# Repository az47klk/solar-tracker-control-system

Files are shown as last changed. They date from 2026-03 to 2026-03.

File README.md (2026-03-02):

# Solar-Tracker: Güneş Paneli Güç Takip ve Kontrol Sistemi

Bu proje, hareketli güneş paneli sistemlerinin güvenli şekilde çalışmaları için, anlık güç takibi yapmak ve çevresel verileri (sıcaklık, zaman vb.) yönetmek amacıyla geliştirilmiş bir gömülü kontrol sistemidir. Proje; donanım tasarımı (PCB), düşük seviyeli sürücü yazılımı ve endüstriyel haberleşme protokollerini kapsamaktadır.

resim

## Teknik Özellikler
Sistem, endüstriyel standart gereksinimleri dikkate alınarak tasarlanmıştır:

* **Kontrol Birimi:** STM32 Mikrodenetleyici tabanlı mimari 
* **Haberleşme:** * **RS485 (Modbus):** Uzak mesafe veri iletimi ve endüstriyel cihaz entegrasyonu.
    * **I2C & UART:** Sensör ve çevre birimleri ile iletişim.
* **Donanım Bileşenleri:**
    * **MAX485:** Diferansiyel sinyal işleme ve gürültü bağışıklığı.
    * **DS1307 RTC:** Gerçek zamanlı saat takibi ile zaman bazlı hareket senaryoları.
    * **JW2 Röle Kontrolü:** Panel hareket mekanizması için güç yönetimi.
    * **128x64 OLED:** Yerel kullanıcı arayüzü ve anlık veri izleme.
* **PCB Tasarımı:** **KiCad** kullanılarak hazırlanan, sinyal bütünlüğü ve güç dağıtımı optimize edilmiş özgün devre kartı.

## Donanım Mimarisi
Proje kapsamında geliştirilen güç takip kartı şu işlevleri yerine getirmektedir:
1.  **Veri Toplama:** Sıcaklık sensörlerinden gelen verilerin işlenmesi.
2.  **Güç Yönetimi:** Röle katmanı üzerinden motor sürücülerin kontrol edilmesi.
3.  **HMI Entegrasyonu:** Sistem durumunun (gerilim, akım, zaman, sıcaklık) OLED ekran üzerinde gösterilmesi.
4.  **Haberleşme Katmanı:** Toplanan verilerin RS485 üzerinden merkezi bir birime aktarılması.

## Dosya Yapısı
* `/Hardware`: KiCad şema ve PCB tasarım dosyaları (Gerber dahil).
* `/Software`: C++ ile geliştirilen kontrol yazılımı ve sürücü kütüphaneleri.

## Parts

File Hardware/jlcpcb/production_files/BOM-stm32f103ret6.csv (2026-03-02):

Comment | Designator | Footprint | LCSC | Quantity
0.5R | R21 | R_2512_6332Metric | C105142 | 1
1.2k | R4 | R_0603_1608Metric | C22765 | 1
1.5M | R23 | R_0603_1608Metric | C1203 | 1
100R | R13,R17 | R_0603_1608Metric | C22775 | 2
100k | R12,R16 | R_0603_1608Metric | C15458 | 2
100nF | C12,C2,C21 | C_0402_1005Metric | C1525 | 3
100nF | C1,C10,C11,C13,C14,C7,C8,C9 | C_0603_1608Metric | C1590 | 8
10k | R2,R6,R8,R9 | R_0603_1608Metric | C15401 | 4
10k | R11,R14,R15,R3,R7 | R_0402_1005Metric | C25531 | 5
10uF | C17,C18,C3 | CP_EIA-3216-18_Kemet-A | C7171 | 3
120R | R5 | R_0603_1608Metric_Pad0.98x0.95mm_HandSolder | C22787 | 1
180R | R19 | R_0603_1608Metric | C22828 | 1
1N4148W | D6 | D_SOD-123 | C2099 | 1
1uF | C15,C19 | C_0603_1608Metric | C1592 | 2
200R | R26 | R_0603_1608Metric | C8218 | 1
20k | R10 | R_0402_1005Metric | C25545 | 1
220uF | C16 | CP_Elec_6.3x7.7 | C3342 | 1
3.3k | R18 | R_0402_1005Metric | C25890 | 1
30pF | C5,C6 | C_0603_1608Metric | C1658 | 2
32768Hz | Y1 | Crystal_SMD_3215-2Pin_3.2x1.5mm | C182057 | 1
330R | R1 | R_0603_1608Metric | C22104 | 1
33uH | L1 | L_Wuerth_HCM-1052 | C9186 | 1
470k | R25 | R_0603_1608Metric | C25599 | 1
680uF | C4 | CP_Elec_12.5x13.5 | C98216 | 1
8MHz_Crystal | Y2 | Crystal_SMD_5032-2Pin_5.0x3.2mm | C115962 | 1
ACPL-P340 | U8 | SO-6L_10x3.84mm_P1.27mm | C74960 | 1
AMS1117-3.3 | U6 | SOT-223-3_TabPin2 | C6186 | 1
AO3400A | Q1 | SOT-23 | C20917 | 1
AT24C512C | U1 | SOP-8_3.76x4.96mm_P1.27mm | C19723714 | 1
Battery_Cell | BT1 | CR2032_battery | C962133 | 1
Conn_01x02 | J2 | PhoenixContact_MSTBA_2,5_2-G-5,08_1x02_P5.08mm_Horizontal | C3697 | 1
Conn_01x03 | J1,J3 | PhoenixContact_MSTBA_2,5_3-G-5,08_1x03_P5.08mm_Horizontal | C8377 | 2
Conn_02x06 | J5 | IDC-Header_2x06_P2.54mm_Vertical | C5307342 | 1
D | D2 | D_SMB | C15874 | 1
DS1307Z+ | U5 | SOIC-8_3.9x4.9mm_P1.27mm | C9868 | 1
DS1621 | U4 | SOIC-8_3.9x4.9mm_P1.27mm | C407894 | 1
INA226 | U9 | VSSOP-10_3x3mm_P0.5mm | C49851 | 1
LED | D1,D3,D4 | LED_0805_2012Metric | C94868 | 3
LM2596S-5 | U7 | TO-263-5_TabPin3 | C2980820 | 1
MAX485ESA+T | U2 | SOIC-8_3.9x4.9mm_P1.27mm | C19738 | 1
SS14 | D5 | D_SMA | C2480 | 1
SS34 | D7 | D_SMA | C8678 | 1
STM32F103RETx | U3 | LQFP-64_10x10mm_P0.5mm | C1337363 | 1
JW2 | RL1 | Relay_DPDT_Panasonic_JW2 |  | 1
Conn_01x05 | J4 | PinHeader_1x05_P2.54mm_Vertical |  | 1

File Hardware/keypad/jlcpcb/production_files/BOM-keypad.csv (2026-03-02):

Comment | Designator | Footprint | LCSC | Quantity
100R | R4,R5,R6,R7 | R_0603_1608Metric | C22775 | 4
100nF | C1,C2,C3,C4 | C_0402_1005Metric | C1525 | 4
10k | R1,R12,R2,R3 | R_0603_1608Metric | C15401 | 4
Conn_01x04_Pin | J1 | PinHeader_1x04_P2.54mm_Vertical | C5116530 | 1
Conn_02x06_Counter_Clockwise | J5 | IDC-Header_2x06_P2.54mm_Vertical | C5224012 | 1
LED | D1,D2,D3,D4 | LED_0805_2012Metric | C2296 | 4
SW_Push | SW4 | SW_PUSH_6mm |  | 1
SW_Push | SW2 | SW_PUSH_6mm |  | 1
SW_Push | SW3 | SW_PUSH_6mm |  | 1
SW_Push | SW1 | SW_PUSH_6mm |  | 1

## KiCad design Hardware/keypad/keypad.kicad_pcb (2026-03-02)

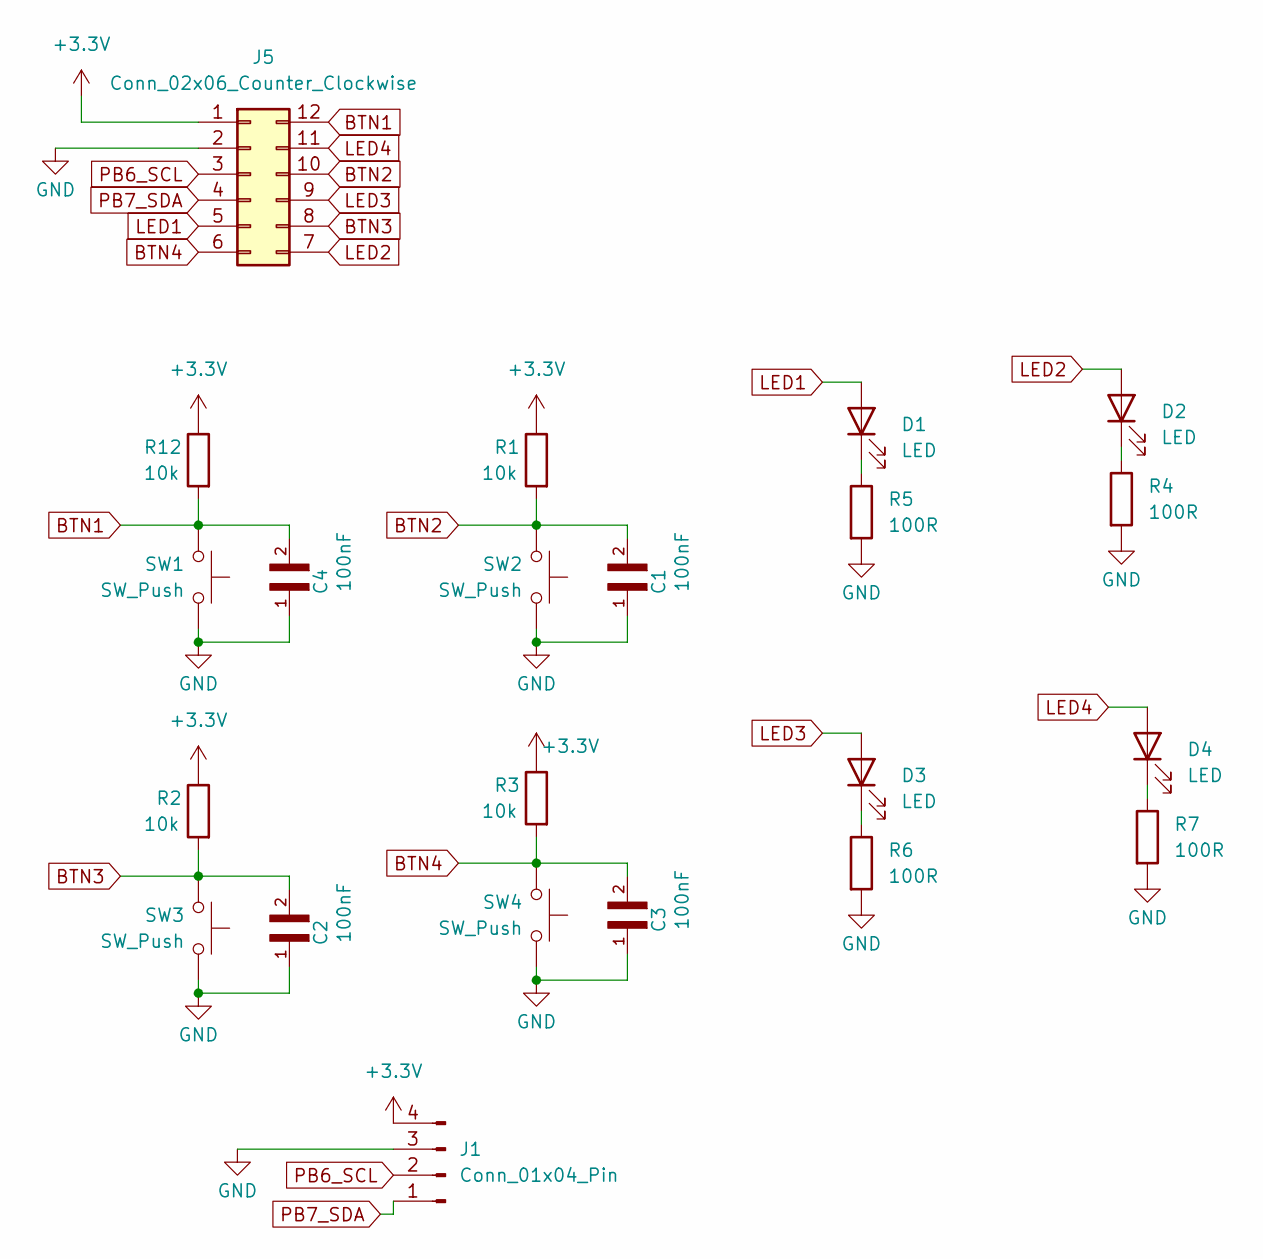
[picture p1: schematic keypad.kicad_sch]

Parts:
C1, C2, C3, C4: 100nF; C_0402_1005Metric
D1, D2, D3, D4: LED; LED_0805_2012Metric
J1: Conn_01x04_Pin; PinHeader_1x04_P2.54mm_Vertical
J5: Conn_02x06_Counter_Clockwise; IDC-Header_2x06_P2.54mm_Vertical
R1, R2, R3, R12: 10k; R_0603_1608Metric
R4, R5, R6, R7: 100R; R_0603_1608Metric
SW1, SW2, SW3, SW4: SW_Push; SW_PUSH_6mm

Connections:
+3.3V: J1.4, J5.1, R1.1, R2.1, R3.1, R12.1
BTN1: C4.2, J5.12, R12.2, SW1.2
BTN2: C1.2, J5.10, R1.2, SW2.2
BTN3: C2.2, J5.8, R2.2, SW3.2
BTN4: C3.2, J5.6, R3.2, SW4.2
GND: C1.1, C2.1, C3.1, C4.1, J1.3, J5.2, R4.2, R5.2, R6.2, R7.2, SW1.1, SW2.1, SW3.1, SW4.1
LED1: D1.2 (A), J5.5
LED2: D2.2 (A), J5.7
LED3: D3.2 (A), J5.9
LED4: D4.2 (A), J5.11
unnamed: D1.1 (K), R5.1
unnamed: D2.1 (K), R4.1
unnamed: D3.1 (K), R6.1
unnamed: D4.1 (K), R7.1
PB6_SCL: J1.2, J5.3
PB7_SDA: J1.1, J5.4

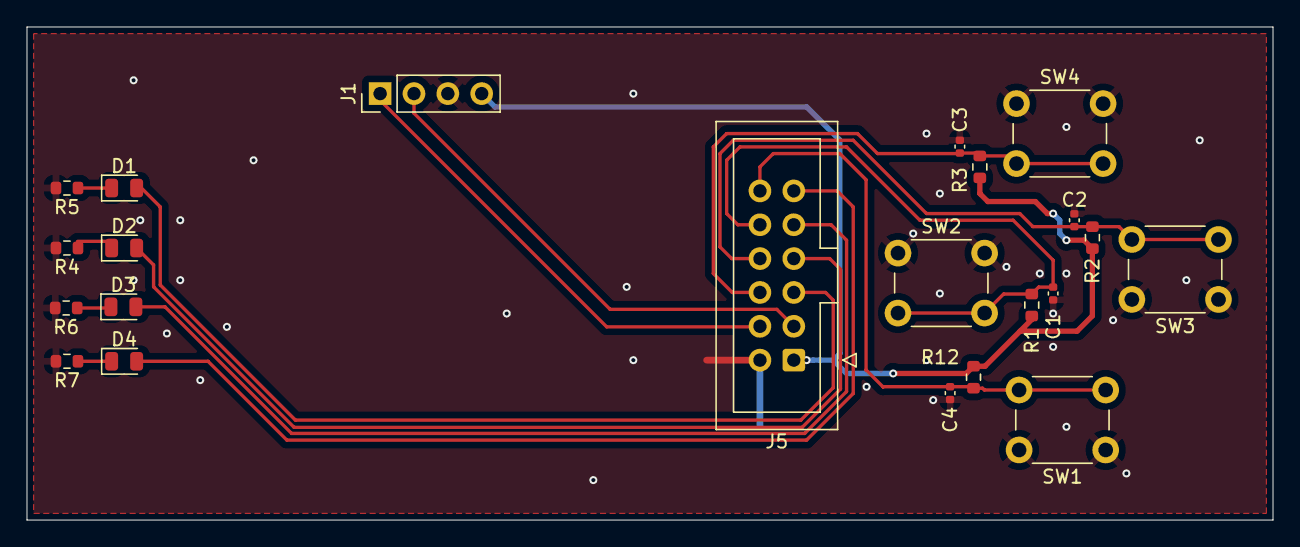
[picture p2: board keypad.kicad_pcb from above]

Board: 2 copper layers, 93.5 x 37.0 mm, 22 parts (0 on the bottom side), 16 nets.

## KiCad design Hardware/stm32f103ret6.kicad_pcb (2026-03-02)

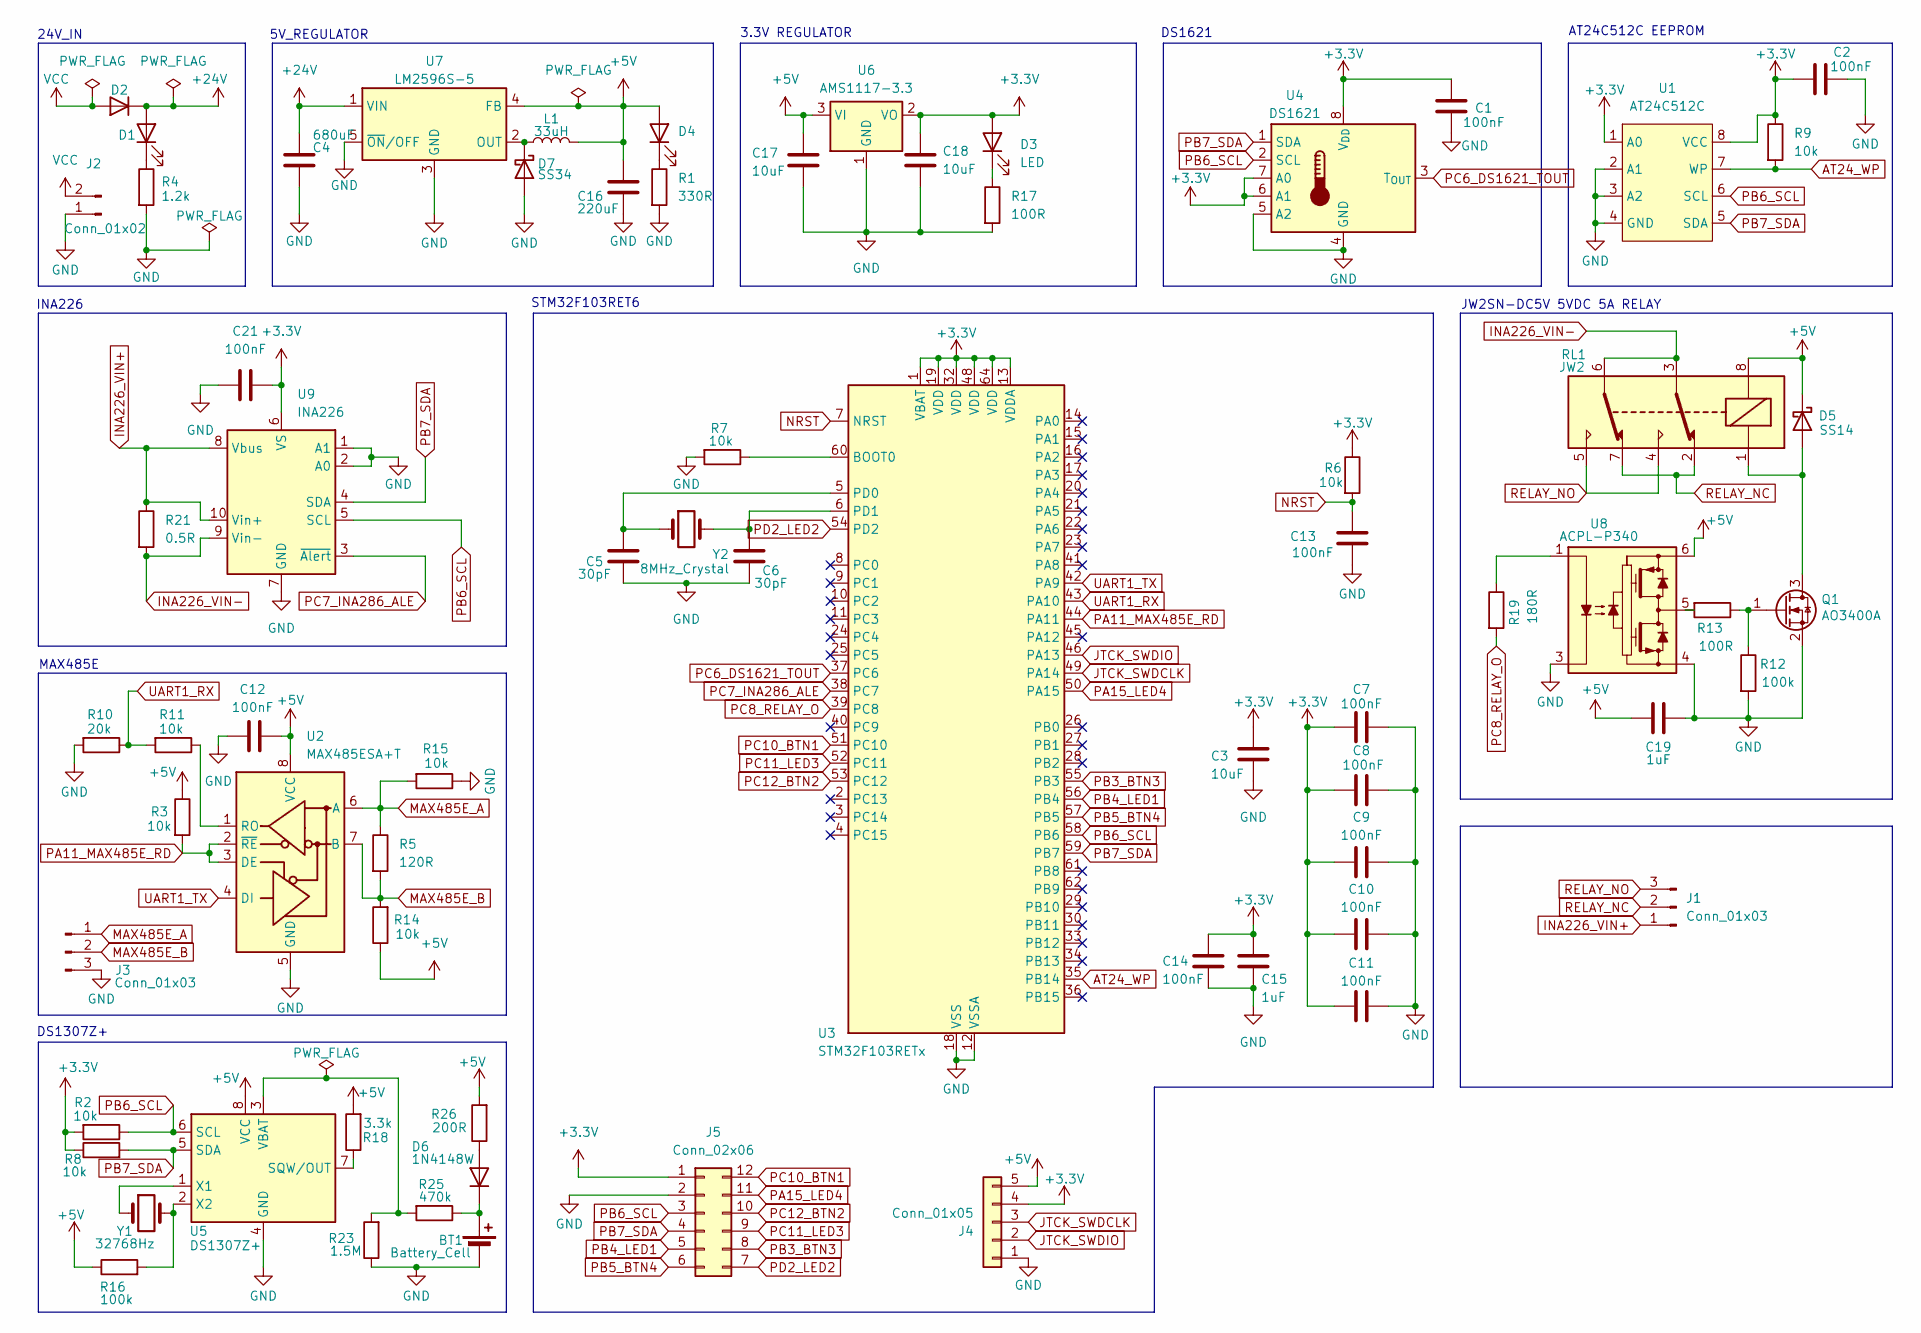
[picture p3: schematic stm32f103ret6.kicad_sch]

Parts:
BT1: Battery_Cell; CR2032_battery
C1, C7, C8, C9, C10, C11, C13, C14: 100nF; C_0603_1608Metric
C2, C12, C21: 100nF; C_0402_1005Metric
C3, C17, C18: 10uF; CP_EIA-3216-18_Kemet-A
C4: 680uF; CP_Elec_12.5x13.5
C5, C6: 30pF; C_0603_1608Metric
C15, C19: 1uF; C_0603_1608Metric
C16: 220uF; CP_Elec_6.3x7.7
D1, D3, D4: LED; LED_0805_2012Metric
D2: D; D_SMB
D5: SS14; D_SMA
D6: 1N4148W; D_SOD-123
D7: SS34; D_SMA
J1, J3: Conn_01x03; PhoenixContact_MSTBA_2,5_3-G-5,08_1x03_P5.08mm_Horizontal
J2: Conn_01x02; PhoenixContact_MSTBA_2,5_2-G-5,08_1x02_P5.08mm_Horizontal
J4: Conn_01x05; PinHeader_1x05_P2.54mm_Vertical
J5: Conn_02x06; IDC-Header_2x06_P2.54mm_Vertical
L1: 33uH; L_Wuerth_HCM-1052
Q1: AO3400A; SOT-23
R1: 330R; R_0603_1608Metric
R2, R6, R8, R9: 10k; R_0603_1608Metric
R3, R7, R11, R14, R15: 10k; R_0402_1005Metric
R4: 1.2k; R_0603_1608Metric
R5: 120R; R_0603_1608Metric_Pad0.98x0.95mm_HandSolder
R10: 20k; R_0402_1005Metric
R12, R16: 100k; R_0603_1608Metric
R13, R17: 100R; R_0603_1608Metric
R18: 3.3k; R_0402_1005Metric
R19: 180R; R_0603_1608Metric
R21: 0.5R; R_2512_6332Metric
R23: 1.5M; R_0603_1608Metric
R25: 470k; R_0603_1608Metric
R26: 200R; R_0603_1608Metric
RL1: JW2; Relay_DPDT_Panasonic_JW2
U1: AT24C512C; SOP-8_3.76x4.96mm_P1.27mm
U2: MAX485ESA+T; SOIC-8_3.9x4.9mm_P1.27mm
U3: STM32F103RETx; LQFP-64_10x10mm_P0.5mm
U4: DS1621; SOIC-8_3.9x4.9mm_P1.27mm
U5: DS1307Z+; SOIC-8_3.9x4.9mm_P1.27mm
U6: AMS1117-3.3; SOT-223-3_TabPin2
U7: LM2596S-5; TO-263-5_TabPin3
U8: ACPL-P340; SO-6L_10x3.84mm_P1.27mm
U9: INA226; VSSOP-10_3x3mm_P0.5mm
Y1: 32768Hz; Crystal_SMD_3215-2Pin_3.2x1.5mm
Y2: 8MHz_Crystal; Crystal_SMD_5032-2Pin_5.0x3.2mm

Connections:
+3.3V: C1.2, C2.1, C3.1, C7.2, C8.2, C9.2, C10.2, C11.2, C14.1, C15.1, C18.1, C21.2, D3.2 (A), J4.4, J5.1, R2.2, R6.1, R8.1, R9.1, U1.1 (A0), U1.8 (VCC), U3.1 (VBAT), U3.13 (VDDA), U3.19 (VDD), U3.32 (VDD), U3.48 (VDD), U3.64 (VDD), U4.6 (A1), U4.7 (A0), U4.8 (V_{DD}), U6.2 (VO), U9.6 (VS)
+5V: C12.2, C16.1, C17.1, C19.2, D4.2 (A), D5.1 (K), J4.5, L1.2, R3.1, R14.1, R16.1, R18.2, R26.2, RL1.8, U2.8 (VCC), U5.8 (VCC), U6.3 (VI), U7.4 (FB), U8.6 (VCC)
+24V: C4.1, D1.2 (A), D2.1 (K), U7.1 (VIN)
AT24_WP: R9.2, U1.7 (WP), U3.35 (PB14)
GND: BT1.2 (-), C1.1, C2.2, C3.2, C4.2, C5.2, C6.2, C7.1, C8.1, C9.1, C10.1, C11.1, C12.1, C13.2, C14.2, C15.2, C16.2, C17.2, C18.2, C19.1, C21.1, D7.2 (A), J2.1, J3.3, J4.1, J5.2, Q1.2 (S), R1.2, R4.2, R7.2, R10.2, R12.2, R15.1, R17.2, R23.1, U1.2 (A1), U1.3 (A2), U1.4 (GND), U2.5 (GND), U3.12 (VSSA), U3.18 (VSS), U3.31 (VSS), U3.47 (VSS), U3.63 (VSS), U4.4 (GND), U4.5 (A2), U5.4 (GND), U6.1 (GND), U7.3 (GND), U7.5 (~ON/OFF), U8.3 (C), U8.4 (VEE), U9.1 (A1), U9.2 (A0), U9.7 (GND)
INA226_VIN+: J1.1, R21.1, U9.8 (Vbus), U9.10 (Vin+)
INA226_VIN-: R21.2, RL1.3, RL1.6, U9.9 (Vin-)
JTCK_SWDCLK: J4.3, U3.49 (PA14)
JTCK_SWDIO: J4.2, U3.46 (PA13)
MAX485E_A: J3.1, R5.1, R15.2, U2.6 (A)
MAX485E_B: J3.2, R5.2, R14.2, U2.7 (B)
NRST: C13.1, R6.2, U3.7 (NRST)
unnamed: BT1.1 (+), D6.1 (K), R25.1
unnamed: D1.1 (K), R4.1
unnamed: D3.1 (K), R17.1
unnamed: D4.1 (K), R1.1
unnamed: D5.2 (A), Q1.3 (D), RL1.1
unnamed: D6.2 (A), R26.1
unnamed: D7.1 (K), L1.1, U7.2 (OUT)
unnamed: Q1.1 (G), R12.1, R13.1
unnamed: R11.1, U2.1 (RO)
unnamed: R7.1, U3.60 (BOOT0)
unnamed: C5.1, U3.5 (PD0), Y2.1
unnamed: C6.1, U3.6 (PD1), Y2.2
unnamed: R18.1, U5.7 (SQW/OUT)
unnamed: R23.2, R25.2, U5.3 (VBAT)
unnamed: U5.1 (X1), Y1.1
unnamed: R16.2, U5.2 (X2), Y1.2
unnamed: R19.1, U8.1 (A)
unnamed: R13.2, U8.5 (VO)
PA11_MAX485E_RD: R3.2, U2.2 (~RE), U2.3 (DE), U3.44 (PA11)
PA15_LED4: J5.11, U3.50 (PA15)
PB3_BTN3: J5.8, U3.55 (PB3)
PB4_LED1: J5.5, U3.56 (PB4)
PB5_BTN4: J5.6, U3.57 (PB5)
PB6_SCL: J5.3, R2.1, U1.6 (SCL), U3.58 (PB6), U4.2 (SCL), U5.6 (SCL), U9.5 (SCL)
PB7_SDA: J5.4, R8.2, U1.5 (SDA), U3.59 (PB7), U4.1 (SDA), U5.5 (SDA), U9.4 (SDA)
PC6_DS1621_TOUT: U3.37 (PC6), U4.3 (T_{OUT})
PC7_INA286_ALE: U3.38 (PC7), U9.3 (~Alert)
PC8_RELAY_O: R19.2, U3.39 (PC8)
PC10_BTN1: J5.12, U3.51 (PC10)
PC11_LED3: J5.9, U3.52 (PC11)
PC12_BTN2: J5.10, U3.53 (PC12)
PD2_LED2: J5.7, U3.54 (PD2)
RELAY_NC: J1.2, RL1.2, RL1.7
RELAY_NO: J1.3, RL1.4, RL1.5
UART1_RX: R10.1, R11.2, U3.43 (PA10)
UART1_TX: U2.4 (DI), U3.42 (PA9)
VCC: D2.2 (A), J2.2

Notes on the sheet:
STM32F103RET6
MAX485E
JW2SN-DC5V 5VDC 5A RELAY
3.3V REGULATOR
5V_REGULATOR
24V_IN
AT24C512C EEPROM
DS1621
DS1307Z+
INA226

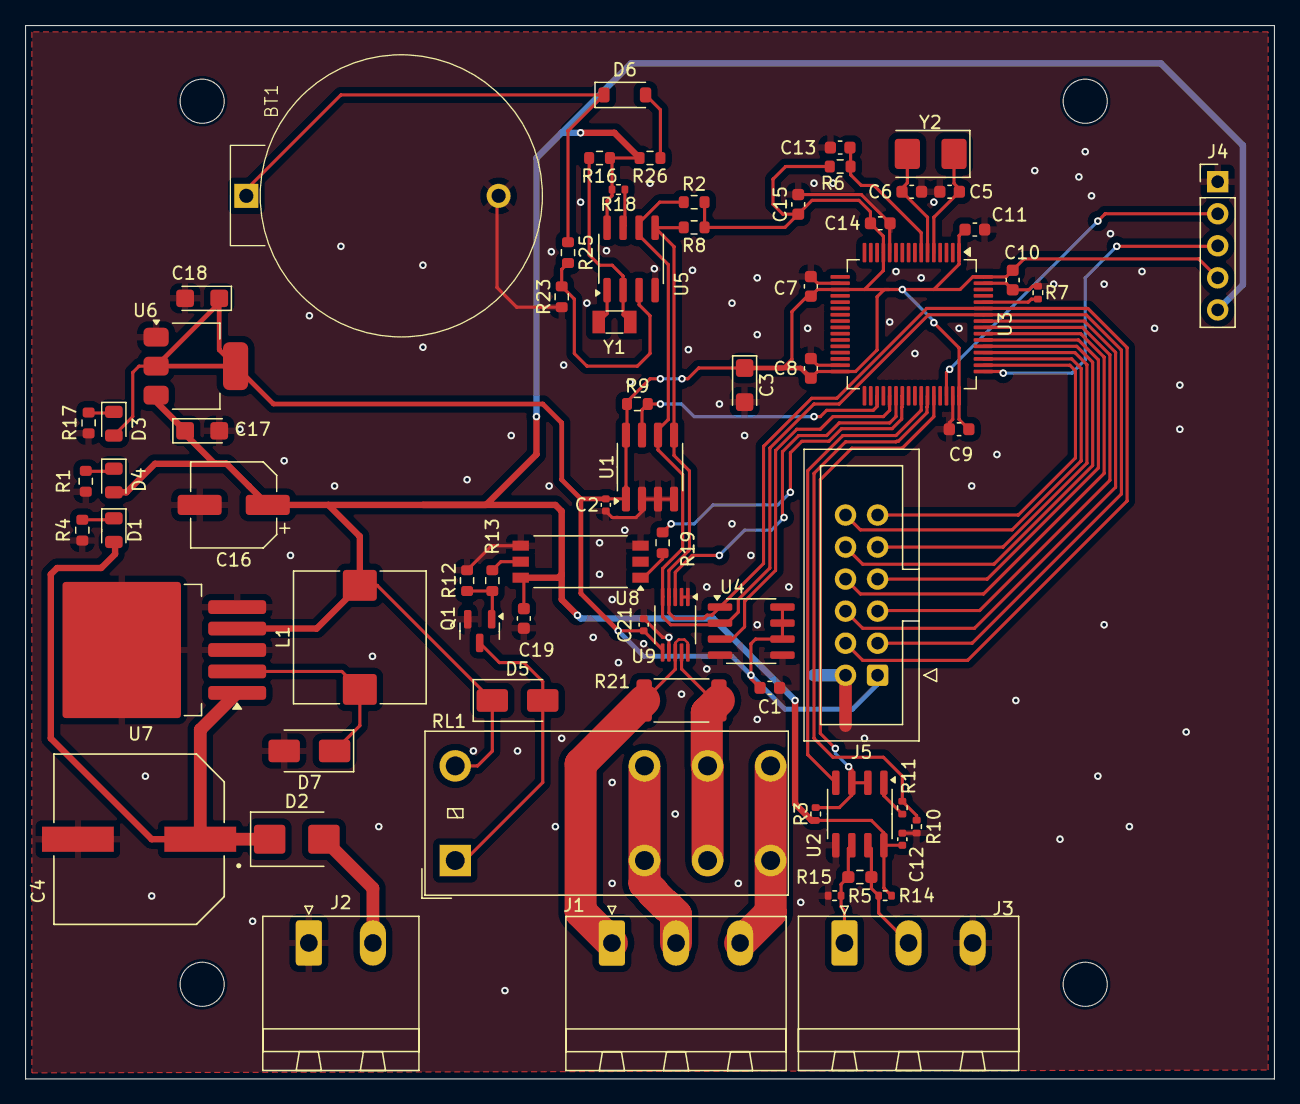
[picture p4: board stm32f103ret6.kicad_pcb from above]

Board: 2 copper layers, 99.0 x 83.5 mm, 70 parts (0 on the bottom side), 49 nets.

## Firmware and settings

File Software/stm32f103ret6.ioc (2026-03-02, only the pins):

Mcu.UserName=STM32F103RETx
PA10.Signal=USART1_RX
PA11.Signal=GPIO_Output
PA13.Signal=SYS_JTMS-SWDIO
PA14.Signal=SYS_JTCK-SWCLK
PA9.Signal=USART1_TX
PB14.Signal=GPIO_Output
PB3.Signal=GPIO_Input
PB4.Signal=GPIO_Output
PB5.Signal=GPIO_Input
PB6.Signal=I2C1_SCL
PB7.Signal=I2C1_SDA
PC10.Signal=GPIO_Input
PC11.Signal=GPIO_Output
PC12.Signal=GPIO_Input
PC6.Signal=GPIO_Output
PC7.Signal=GPIO_Input
PC8.Signal=GPIO_Input
PD0-OSC_IN.Signal=RCC_OSC_IN
PD1-OSC_OUT.Signal=RCC_OSC_OUT
PD2.Signal=GPIO_Output

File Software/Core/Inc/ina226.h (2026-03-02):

/*
 * ina226.cpp
 *
 *  Created on: Aug 4, 2025
 *      Author: az47klk
 */

#ifndef __INA226_H
#define __INA226_H

#include "stm32f1xx_hal.h"
#include <stdbool.h>

// pin definitions
#define INA226_PIN_GND      0
#define INA226_PIN_VS       1
#define INA226_PIN_SDA      2
#define INA226_PIN_SCL      3

// registers
#define INA226_REG_CONF     0x00
#define INA226_REG_SHNT     0x01
#define INA226_REG_BUS      0x02
#define INA226_REG_PWR      0x03
#define INA226_REG_CUR      0x04
#define INA226_REG_CLB      0x05
#define INA226_REG_MSK      0x06
#define INA226_REG_ALIM     0x07
#define INA226_REG_MID      0xFE
#define INA226_REG_DID      0xFF

typedef struct {
	uint8_t INA226_Address;
	I2C_HandleTypeDef *hi2c;
	float current_lsb;

	GPIO_TypeDef *GPIOx;
	uint16_t GPIO_PIN_x;

} INA226;

#define default_INA226_Config(a) INA226_Config(a, INA226_SHUNT_VOLTAGE_ENABLE, INA226_BUS_VOLTAGE_ENABLE, INA226_CONF_CONTINIOUS, INA226_CONF_CONV_TIME_8_244MS, INA226_CONF_CONV_TIME_8_244MS, INA226_CONF_AVG_NUM_1);


#define INA226_ALARM_SHUNT_OVER_VOLTAGE  (1 << 15)
#define INA226_ALARM_SHUNT_UNDER_VOLTAGE (1 << 14)
#define INA226_ALARM_BUS_OVER_VOLTAGE    (1 << 13)
#define INA226_ALARM_BUS_UNDER_VOLTAGE   (1 << 12)
#define INA226_ALARM_POWER_OVERLOAD      (1 << 11)
#define INA226_ALARM_CONVERSION_READY    (1 << 10)
#define INA226_ALARM_ALERT_FUNC_FLAG     (1 << 4)
#define INA226_ALARM_CONV_READY_FLAG     (1 << 3)
#define INA226_ALARM_MATH_OVERFLOW_FLAG  (1 << 2)
#define INA226_ALARM_ALERT_POLARITY      (1 << 1)
#define INA226_ALARM_ALERT_LATCH_EN      1


// avg config
typedef enum {
      INA226_CONF_AVG_NUM_1    = 0b000,
      INA226_CONF_AVG_NUM_4    = 0b001,
      INA226_CONF_AVG_NUM_16   = 0b010,
      INA226_CONF_AVG_NUM_64   = 0b011,
      INA226_CONF_AVG_NUM_128  = 0b100,
      INA226_CONF_AVG_NUM_256  = 0b101,
      INA226_CONF_AVG_NUM_512  = 0b110,
      INA226_CONF_AVG_NUM_1024 = 0b111,
} INA226_CONF_AVG;



//convertion time config
typedef enum {
	  INA226_CONF_CONV_TIME_140US   = 0b000,
	  INA226_CONF_CONV_TIME_204US   = 0b001,
	  INA226_CONF_CONV_TIME_332US   = 0b010,
	  INA226_CONF_CONV_TIME_588US   = 0b011,
	  INA226_CONF_CONV_TIME_1_1MS   = 0b100,
	  INA226_CONF_CONV_TIME_2_116MS = 0b101,
	  INA226_CONF_CONV_TIME_4_156MS = 0b110,
	  INA226_CONF_CONV_TIME_8_244MS = 0b111
} INA226_CONF_CONV_TIME;

// mode config
typedef enum {
	INA226_CONF_TRIGGERED = 0,
	INA226_CONF_CONTINIOUS = 1
} INA226_CONF_TRIG;

typedef enum {
	INA226_BUS_VOLTAGE_DISABLE = 0,
	INA226_BUS_VOLTAGE_ENABLE = 1
} INA226_CONF_BUS_VOLTAGE;


typedef enum {
	INA226_SHUNT_VOLTAGE_DISABLE = 0,
	INA226_SHUNT_VOLTAGE_ENABLE = 1
} INA226_CONF_SHUNT_VOLTAGE;


void INA226_Set_Address(INA226*, I2C_HandleTypeDef*, uint8_t, uint8_t);

int INA226_WriteRegister(INA226*, uint8_t, uint16_t);
uint16_t INA226_ReadRegister(INA226*, uint8_t);

void INA226_Config(INA226 *INA226_P, INA226_CONF_SHUNT_VOLTAGE , INA226_CONF_BUS_VOLTAGE, INA226_CONF_TRIG, INA226_CONF_CONV_TIME, INA226_CONF_CONV_TIME, INA226_CONF_AVG);

float INA226_ReadShuntVoltage(INA226*);
float INA226_ReadBusVoltage(INA226*);
float INA226_ReadPower(INA226*);
float INA226_ReadCurrent(INA226*);


void INA226_SetAlarmMode(INA226*, uint16_t[]);
void INA226_SetAlarmPin(INA226*, GPIO_TypeDef *, uint16_t);
void INA226_SetCalibrationReg(INA226 *, float, float);

void INA226_SetAlarmLimitShuntVoltage(INA226 *, float);
void INA226_SetAlarmLimitBusVoltage(INA226 *, float);
void INA226_SetAlarmLimitCurrent(INA226 *, float);
void INA226_SetAlarmLimitPower(INA226 *, float);

bool INA226_ReadAlarmPin(INA226*);


#endif
